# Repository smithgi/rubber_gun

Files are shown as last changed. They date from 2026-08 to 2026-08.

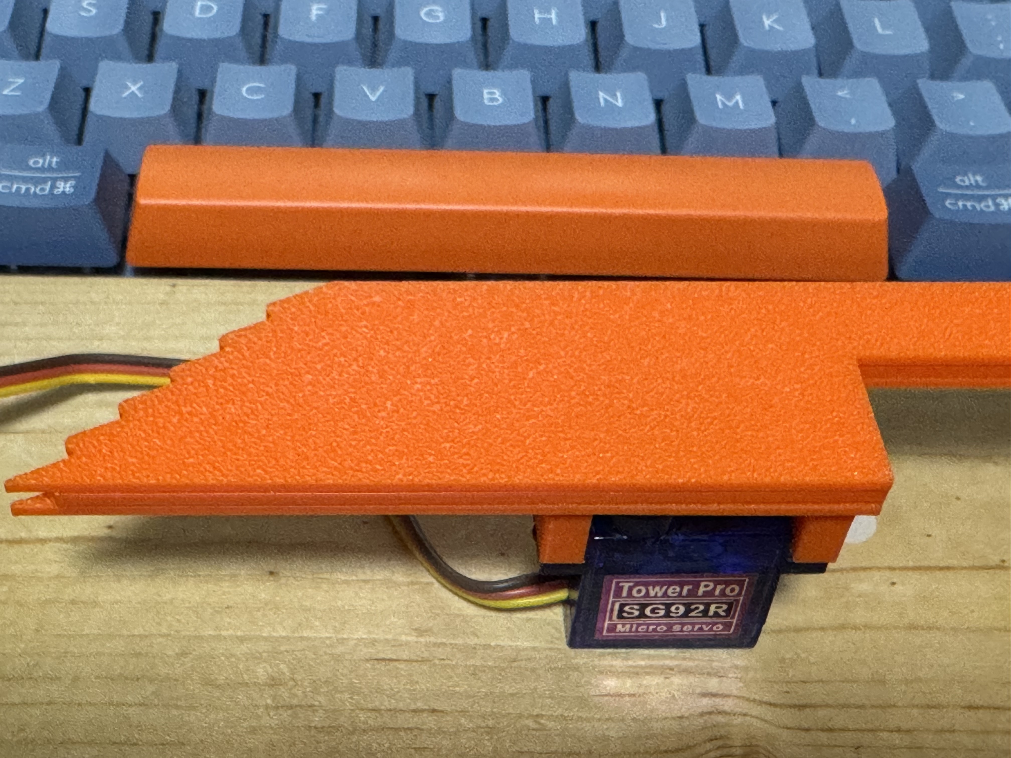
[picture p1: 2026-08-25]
3dParts/Slider Rubber Band Gun - 6731580/images/bcf5f3ab-10ea-41df-92d6-8c3bb40bf381.jpg

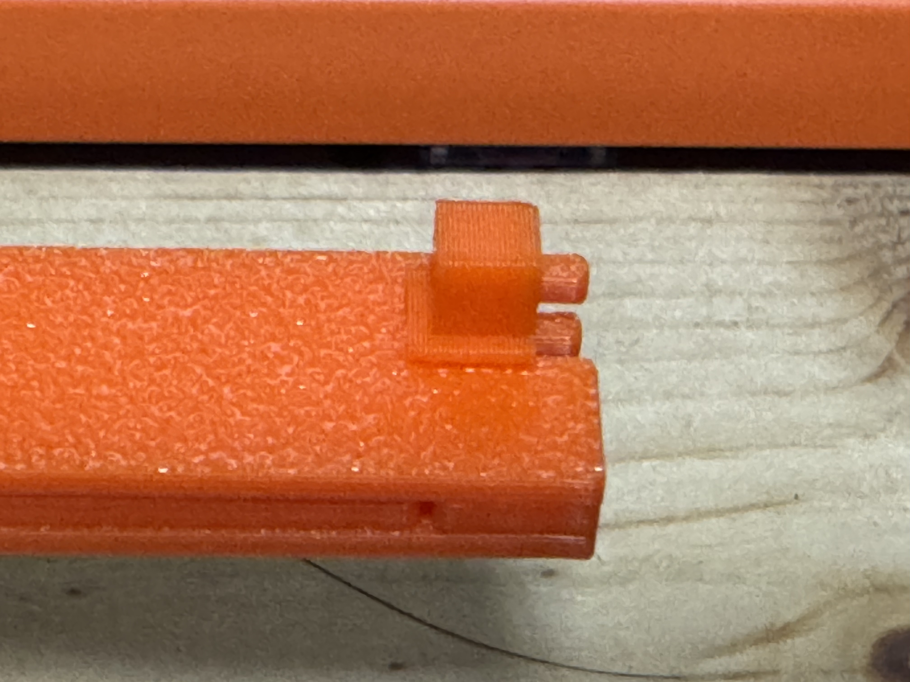
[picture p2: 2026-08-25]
3dParts/Slider Rubber Band Gun - 6731580/images/5f8fa5fe-a7aa-4b6f-bb32-10ab86485eba.jpg

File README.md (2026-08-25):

# Rubber-band radar gun

Standalone rubber-band turret: an RP2040 aims two servos from an RD-03D radar module and fires a third servo on a printed 5-shot slider gun.

Firmware lives in [`RPI2040/`](RPI2040/). Print files live in [`3dParts/`](3dParts/). The Python host and ESP32 sketch are not required.

## What you need

| Item | Notes |
|---|---|
| RP2040-Zero (or Pico) | USB-C powers the MCU only |
| RD-03D radar | UART to GP0 / GP1 |
| 3× micro servos | 9 g SG90 class. SG92R (or equivalent high-torque) is recommended for the trigger |
| External 5 V supply, **≥ 2 A** | Radar VCC + all three servo VCC. Do not power servos from the RP2040 3.3 V pin |
| Printed pan/tilt mount | [`3dParts/2axis_servo.3mf`](3dParts/2axis_servo.3mf) |
| Printed slider gun | [`3dParts/Slider Rubber Band Gun - 6731580/`](3dParts/Slider%20Rubber%20Band%20Gun%20-%206731580/) |
| Rubber bands | Up to 5 on the staircase muzzle |

## Print

### 2-axis servo mount

Open [`3dParts/2axis_servo.3mf`](3dParts/2axis_servo.3mf) in Bambu Studio (or another slicer that reads 3MF). The plate contains three parts:

| Part | Role |
|---|---|
| `base.stl` | Pan/tilt base |
| `HolderL.stl` | Left servo holder |
| `HolderR.stl` | Right servo holder |

The bundled slice is **0.20 mm Standard** on a **Bambu Lab A1**, 0.4 mm nozzle, textured PEI plate:

- Filament: PLA
- Layer height: 0.2 mm
- Walls: 2
- Infill: 15% zig-zag
- Top / bottom shells: 5 / 3
- Supports: tree (auto), slim
- Nozzle / bed: 220 °C / 65 °C

On another printer, match those settings as closely as you can. Print the holders with their flat faces on the bed.

### Slider rubber-band gun

Print the four STLs in [`3dParts/Slider Rubber Band Gun - 6731580/files/`](3dParts/Slider%20Rubber%20Band%20Gun%20-%206731580/files/):

| File | Role |
|---|---|
| `InnerPlate.stl` | Inner plate; servo mounts here |
| `OuterPlate.stl` | Outer plate |
| `TriggerPlate.stl` | Sliding trigger plate |
| `MuzzleRetainer.stl` | Retainer on the muzzle |

Same PLA / 0.2 mm settings work. Print the plates flat on the bed.

This gun is [Slider Rubber Band Gun by Kanten_Namako](https://www.thingiverse.com/thing:6731580) (CC BY-NC-SA). Photos of the assembled plates are in [`3dParts/Slider Rubber Band Gun - 6731580/images/`](3dParts/Slider%20Rubber%20Band%20Gun%20-%206731580/images/).

## Mechanical assembly

### Pan / tilt (TURN + UP)

1. Fit two SG90-class servos into `HolderL` and `HolderR`.
2. Mount the holders on `base` so one servo yaws (TURN, horizontal) and the other pitches (UP, vertical).
3. Attach the slider gun to the moving holder so the muzzle points forward.

On boot the firmware homes UP to `0°` and TURN to `90°`. Mount horns so those angles look like “level and centered.” If the turret is inverted or offset, change `GUN_H_CALIBRATION` and `GUN_V_CALIBRATION` in [`RPI2040/code.py`](RPI2040/code.py).

### Trigger gun

1. Fix the trigger servo on the **inner plate**.
2. Command the servo to **90°**, then attach a servo horn as in the Thingiverse photos.
3. Put the **trigger plate** on the inner plate, then attach the **outer plate**.
4. Attach the **muzzle retainer** to the muzzle.
5. Check motion by sweeping the servo from **90° to 120°**. That should release a band. If torque is weak, load fewer bands.
6. Load rubber bands from the **bottom** of the staircase to the **top**. Maximum five.

Firmware defaults are `TRIGGER_IDLE_DEG = 0` and `TRIGGER_FIRE_DEG = 50`. After the horn is locked at 90°, edit those two constants (or send `{"trigger_pos": …}` over USB) so idle holds the slider and fire matches the 90°→120° release.

## Firmware

1. Install [CircuitPython](https://circuitpython.org/) on the RP2040 so it mounts as `CIRCUITPY`.
2. Copy [`RPI2040/code.py`](RPI2040/code.py) onto that drive. No extra libraries are required (`board`, `busio`, `pwmio` are built in).
3. Leave the board on USB-C. Auto aim/shoot is on at boot (`GUN_ENABLED_ON_BOOT = True`).

Aim math (same policy as the old host):

```
v = distance_mm / 100 + GUN_V_CALIBRATION
h = 180 - radar_angle + GUN_H_CALIBRATION
```

If the radar angle changes, the gun aims. If the next frame reports the same angle, it fires a burst (`BURST_NUM = 2`).

## Wiring

Full diagram: [`RPI2040/wiring.svg`](RPI2040/wiring.svg) / [`RPI2040/wiring.png`](RPI2040/wiring.png).

| Function | RP2040 pin | Goes to |
|---|---|---|
| Radar TX | GP0 | RD-03D **RX** |
| Radar RX | GP1 | RD-03D **TX** |
| Turn servo (h) | GP2 | TURN servo **SIG** (orange / yellow) |
| Up servo (v) | GP3 | UP servo **SIG** (orange / yellow) |
| Trigger servo | GP4 | TRIGGER servo **SIG** (orange / yellow) |
| Common ground | GND | PSU GND + radar GND + all 3 servo GND (brown / black) |
| Servo / radar power | external **5 V** | radar VCC + all 3 servo VCC (red) |

```
                    USB-C (powers the RP2040 only)
                         │
                         ▼
                   ┌─────────────┐
  RD-03D TX ──────►│ GP1  RX     │
  RD-03D RX ◄──────│ GP0  TX     │
                   │             │ GP2 ── SIG ── TURN servo
                   │ RP2040-Zero │ GP3 ── SIG ── UP servo
                   │             │ GP4 ── SIG ── TRIGGER servo
                   │ GND         │
                   └──────┬──────┘
                          │
     common GND ──────────┼────────── PSU GND
                          │
     5V PSU (≥2A) ── +5V ─┴── radar VCC + 3× servo VCC (red)

     Every brown/black servo wire → the same GND star.
     Do not power servos from the RP2040 3.3 V pin.
```

UART names are crossed on purpose: module TX goes to MCU RX. Radar baud is 256000.

### Power rules

1. Tie every GND together: PSU, RP2040, RD-03D, and all three servos. Without a common ground the PWM signals will not reference the servos.
2. Keep the RP2040 on USB-C. Power the three servos and the RD-03D VCC from the **separate 5 V, ≥ 2 A** supply.
3. Never feed servo VCC from the RP2040 3.3 V pin. Current spikes will brown-out the MCU.
4. 3.3 V PWM on GP2 / GP3 / GP4 is enough for most hobby servos.

## USB serial (optional)

Open the CircuitPython REPL / serial monitor:

| Command | Effect |
|---|---|
| `start` or `{"start":true}` | enable auto aim/shoot |
| `stop` or `{"stop":true}` | disable auto aim/shoot |
| `{"h":90,"v":40}` | manual aim |
| `{"shoot":true}` | one trigger pull |
| `{"trigger_pos":50}` | set trigger servo degrees |

Radar frames still print as JSON arrays.

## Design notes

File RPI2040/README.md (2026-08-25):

# RP2040 standalone radar gun

Runs the whole stack on one RP2040 (RP2040-Zero / Pico):

- talk to the RD-03D on UART
- aim `TURN` + `UP` servos
- fire the `TRIGGER` servo

The Python host (`main.py`) and the ESP32 sketch (`arduino_gun.ino`) are not needed.

Copy `code.py` onto the CircuitPython `CIRCUITPY` drive.

## Pin map

| Function | RP2040 pin | Goes to |
|---|---|---|
| Radar TX | GP0 | RD-03D **RX** |
| Radar RX | GP1 | RD-03D **TX** |
| Turn servo (h) | GP2 | Turn servo **SIG** (orange) |
| Up servo (v) | GP3 | Up servo **SIG** (orange) |
| Trigger servo | GP4 | Trigger servo **SIG** (orange) |
| Common ground | GND | PSU GND + radar GND + all 3 servo GND |
| Servo / radar power | external **5V** | radar VCC + all 3 servo VCC (red) |

See `wiring.svg` and `wiring.png`.

## Wiring sketch

```
                    USB-C (powers the RP2040 only)
                         │
                         ▼
                   ┌─────────────┐
  RD-03D TX ──────►│ GP1  RX     │
  RD-03D RX ◄──────│ GP0  TX     │
                   │             │ GP2 ── SIG ── TURN servo
                   │ RP2040-Zero │ GP3 ── SIG ── UP servo
                   │             │ GP4 ── SIG ── TRIGGER servo
                   │ GND         │
                   └──────┬──────┘
                          │
     common GND ──────────┼────────── PSU GND
                          │
     5V PSU (≥2A) ── +5V ─┴── radar VCC + 3× servo VCC (red)

     Every brown/black servo wire → the same GND star.
     Do not power servos from the RP2040 3.3V pin.
```

UART names are crossed on purpose: module TX goes to MCU RX.

## Power

- Keep the RP2040 on USB-C.
- Power the three servos (and the RD-03D VCC) from a **separate 5 V supply, 2 A or more**.
- Tie all grounds together. Without a common GND the PWM signals will not reference the servos.

## Aim / shoot (same as `main.py`)

```
v = distance_mm / 100 + GUN_V_CALIBRATION
h = 180 - radar_angle + GUN_H_CALIBRATION
```

If the radar angle changes, the gun aims. If the next frame reports the same angle, it fires a burst.

Defaults match `.env`: `GUN_H_CALIBRATION=-30`, `GUN_V_CALIBRATION=-10`, `BURST_NUM=2`. Edit the constants at the top of `code.py`.

## USB serial (optional)

115200-style CircuitPython REPL / serial monitor:

| Command | Effect |
|---|---|
| `start` or `{"start":true}` | enable auto aim/shoot |
| `stop` or `{"stop":true}` | disable auto aim/shoot |
| `{"h":90,"v":40}` | manual aim |
| `{"shoot":true}` | one trigger pull |
| `{"trigger_pos":50}` | set trigger servo degrees |

Radar frames still print as JSON arrays, same as the old RP2040 bridge.

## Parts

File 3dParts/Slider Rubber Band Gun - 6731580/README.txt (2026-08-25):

Slider Rubber Band Gun by Kanten_Namako on Thingiverse: https://www.thingiverse.com/thing:6731580

Summary:
A servo motor (SG90 sized) operated 5-shot rubber band gunUsing high torque servo, SG92R or equivalent is recommended.Fix the servo motor on the inner plate and rotate the servo to the 90° position, then attach a servo horn as shown in the picture.Put the trigger plate on the inner plate, then attach outer plate. Attach a muzzle retainer to the muzzle.Check the function by moving the servo from 90° to 120° .Load the rubber bands from the bottom of the staircase-shaped component to the top.A maximum of five rubber bands can be attached.To release the rubber bands, move the servo motor from 90° to 120°.https://youtu.be/MrI2VKSIGMsIf the torque of the servo motor is weak, it can be operated by reducing the number of rubber bands.

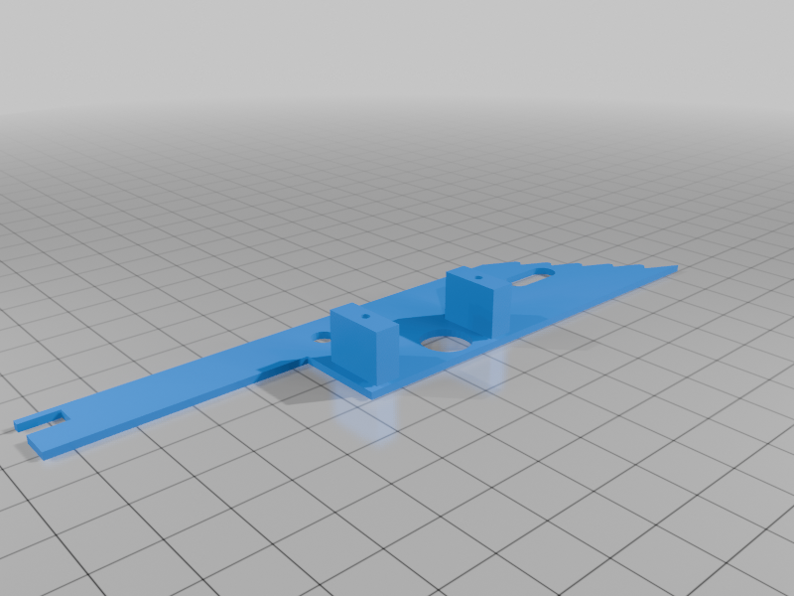
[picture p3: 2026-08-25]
3dParts/Slider Rubber Band Gun - 6731580/images/c03b1915-364d-412d-94fc-ef0b91e72bb4.png

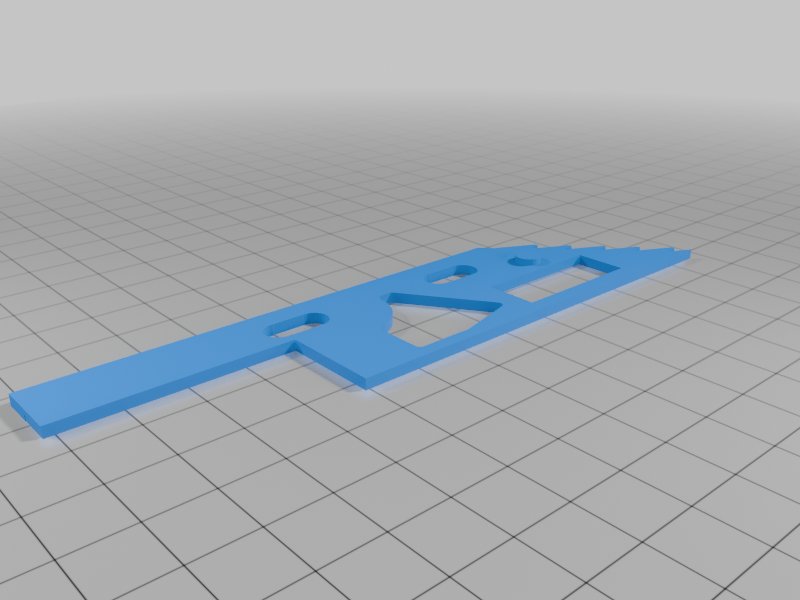
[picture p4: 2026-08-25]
3dParts/Slider Rubber Band Gun - 6731580/images/888463a6-bb99-47a2-ad43-ac800f5a4983.png

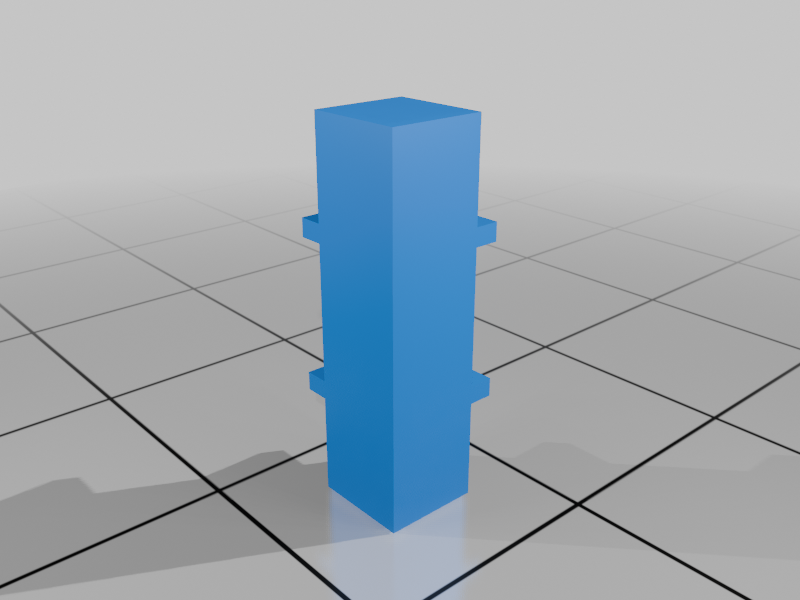
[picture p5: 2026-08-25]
3dParts/Slider Rubber Band Gun - 6731580/images/fcaf6c9f-c65c-43a0-b7bd-5645cbccdeec.png

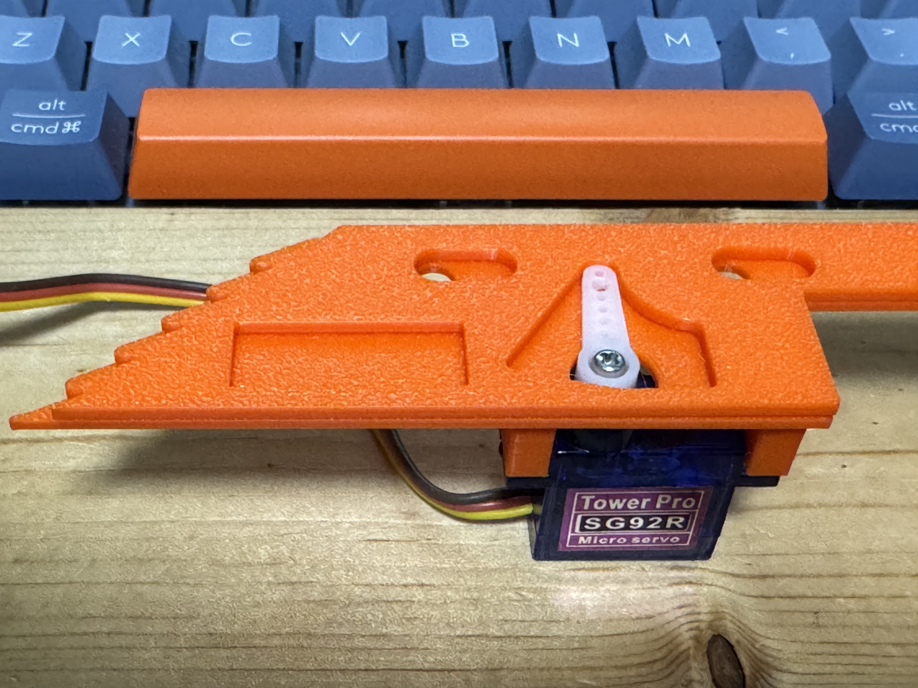
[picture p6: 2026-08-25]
3dParts/Slider Rubber Band Gun - 6731580/images/9d21aa52-659c-4183-8837-1a03f21f6c0c.jpg

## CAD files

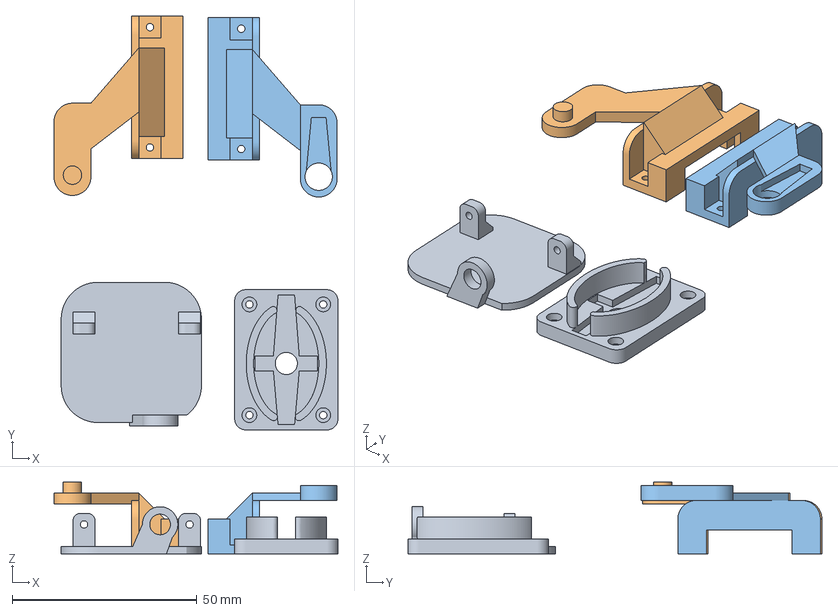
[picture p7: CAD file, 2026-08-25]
3dParts/2axis_servo.3mf
76.9 x 112.1 x 19.5 mm
base.stl
HolderL.stl
HolderR.stl

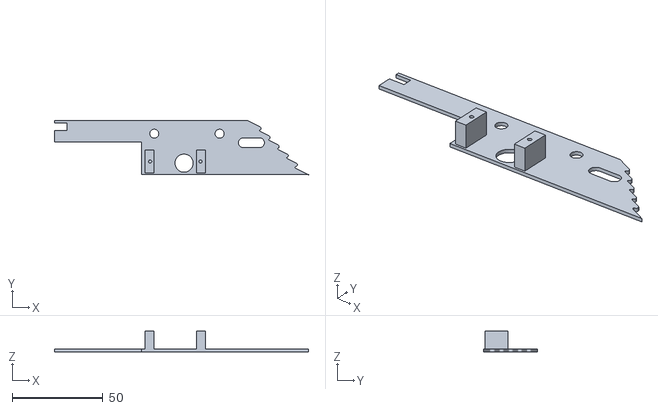
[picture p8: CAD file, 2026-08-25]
3dParts/Slider Rubber Band Gun - 6731580/files/InnerPlate.stl
140.0 x 30.0 x 11.5

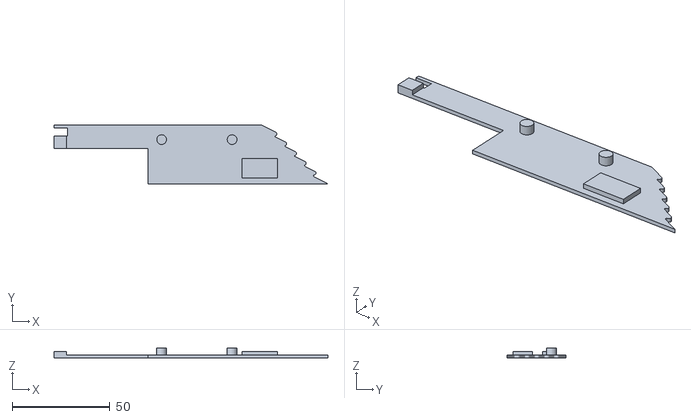
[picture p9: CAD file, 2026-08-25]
3dParts/Slider Rubber Band Gun - 6731580/files/OuterPlate.stl
140.0 x 30.0 x 5.00

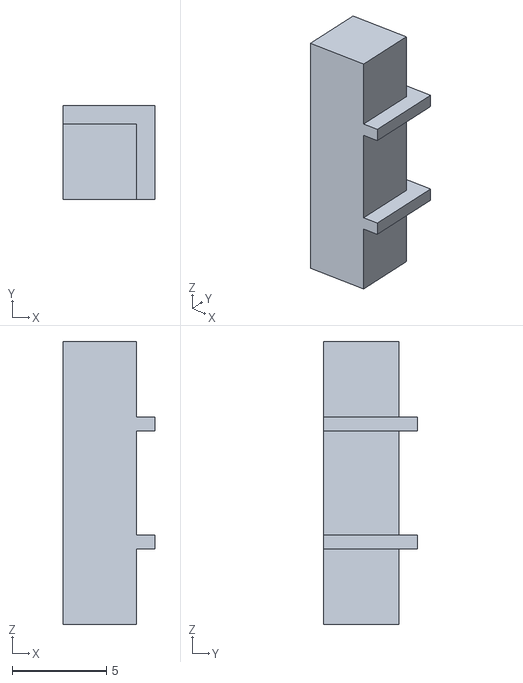
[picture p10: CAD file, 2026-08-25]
3dParts/Slider Rubber Band Gun - 6731580/files/MuzzleRetainer.stl
4.90 x 5.00 x 15.0

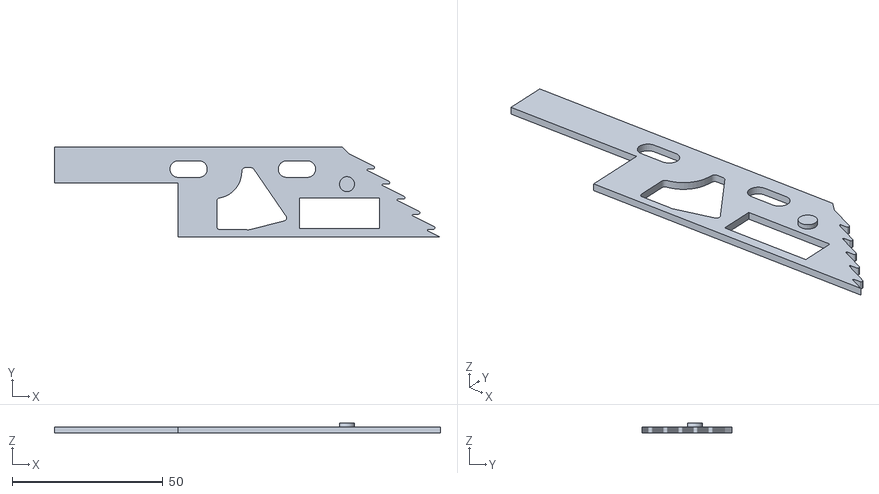
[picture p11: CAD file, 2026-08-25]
3dParts/Slider Rubber Band Gun - 6731580/files/TriggerPlate.stl
128.2 x 30.0 x 3.28

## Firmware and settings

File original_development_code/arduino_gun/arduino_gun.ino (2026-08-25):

#include <ESP32Servo.h>
#include <string.h>

Servo upServo;
Servo turnServo;
Servo triggerServo;

const int SERVO1_PIN = 18;
const int SERVO2_PIN = 19;
const int TRIGGER_SERVO_PIN = 5;

const int TRIGGER_FIRE_DEG = 50;
const int TRIGGER_IDLE_DEG = 0;

int upServoPos = 90;
int turnServoPos = 90;
int triggerServoPos = TRIGGER_IDLE_DEG;

int upServoStartPos = 0;
int turnServoStartPos = 90;

int servoSpeed = 1;

bool useFastMovement = true;

// UART command buffer: {"h":90,"v":90}
#define CMD_BUFFER_LEN 64
char cmdBuffer[CMD_BUFFER_LEN];

bool parseJsonAngles(char* buf, int* turnAngle, int* upAngle) {
  // Format: {"h":<angle>,"v":<angle>}
  int h = -1, v = -1;
  char* p;

  if ((p = strstr(buf, "\"h\":")) != NULL || (p = strstr(buf, "\"H\":")) != NULL) {
    p += 4;  // skip past "h":
    h = atoi(p);
  }
  if ((p = strstr(buf, "\"v\":")) != NULL || (p = strstr(buf, "\"V\":")) != NULL) {
    p += 4;  // skip past "v":
    v = atoi(p);
  }

  if (h >= 0 && h <= 180 && v >= 0 && v <= 180) {
    *turnAngle = h;
    *upAngle = v;
    return true;
  }
  return false;
}

bool parseShoot(char* buf) {
  char* p = strstr(buf, "\"shoot\":");
  if (p == NULL) {
    p = strstr(buf, "\"SHOOT\":");
  }
  if (p == NULL) return false;
  p += 8;
  while (*p == ' ' || *p == '\t') p++;
  return strncmp(p, "true", 4) == 0;
}

bool parseTriggerPos(char* buf, int* deg) {
  char* p = strstr(buf, "\"trigger_pos\"");
  if (p == NULL) p = strstr(buf, "\"TRIGGER_POS\"");
  if (p == NULL) return false;
  p = strchr(p, ':');
  if (p == NULL) return false;
  p++;
  while (*p == ' ' || *p == '\t') p++;
  int v = atoi(p);
  if (v >= 0 && v <= 180) {
    *deg = v;
    return true;
  }
  return false;
}

void fireTrigger() {
  triggerServo.write(TRIGGER_FIRE_DEG);
  triggerServoPos = TRIGGER_FIRE_DEG;
  delay(500);
  triggerServo.write(TRIGGER_IDLE_DEG);
  triggerServoPos = TRIGGER_IDLE_DEG;
}

void setup() {
  Serial.begin(115200);

  upServo.setPeriodHertz(50);
  turnServo.setPeriodHertz(50);
  triggerServo.setPeriodHertz(50);

  upServo.attach(SERVO1_PIN, 500, 2400);
  turnServo.attach(SERVO2_PIN, 500, 2400);
  triggerServo.attach(TRIGGER_SERVO_PIN, 500, 2400);

  upServo.write(upServoPos);
  turnServo.write(turnServoPos);
  triggerServo.write(TRIGGER_IDLE_DEG);
  triggerServoPos = TRIGGER_IDLE_DEG;

  moveSmooth(upServo, upServoPos, upServoStartPos, servoSpeed);
  moveSmooth(turnServo, upServoPos, turnServoStartPos, servoSpeed);

  delay(1000);
}

void loop() {
  // Read UART commands: {"h":90,"v":90}
  if (Serial.available() > 0) {
    int idx = 0;
    memset(cmdBuffer, 0, CMD_BUFFER_LEN);

    while (Serial.available() > 0 && idx < CMD_BUFFER_LEN - 1) {
      char c = Serial.read();
      if (c == '\n' || c == '\r') break;
      cmdBuffer[idx++] = c;
    }
    cmdBuffer[idx] = '\0';

    if (idx > 0) {
      int newTurn, newUp;
      int triggerDeg;
      bool anglesOk = parseJsonAngles(cmdBuffer, &newTurn, &newUp);
      bool shoot = parseShoot(cmdBuffer);
      bool triggerPosOk = parseTriggerPos(cmdBuffer, &triggerDeg);

      if (!anglesOk && !shoot && !triggerPosOk) {
        Serial.println("{\"err\":\"invalid\"}");
      } else {
        if (anglesOk) {
          if (useFastMovement) {
            moveFast(turnServo, newTurn);
            turnServoPos = newTurn;

            moveFast(upServo, newUp);
            upServoPos = newUp;

            Serial.printf("{\"h\":%d,\"v\":%d}\n", newTurn, newUp);
          } else {
            moveSmooth(turnServo, turnServoPos, newTurn, servoSpeed);
            turnServoPos = newTurn;

            moveSmooth(upServo, upServoPos, newUp, servoSpeed);
            upServoPos = newUp;

            Serial.printf("{\"h\":%d,\"v\":%d}\n", turnServoPos, upServoPos);
          }
        }
        if (triggerPosOk) {
          moveFast(triggerServo, triggerDeg);
          triggerServoPos = triggerDeg;
        }
        if (shoot) {
          fireTrigger();
        }
        if (!anglesOk) {
          if (triggerPosOk && shoot) {
            Serial.printf("{\"trigger_pos\":%d,\"shoot\":true}\n", triggerDeg);
          } else if (triggerPosOk) {
            Serial.printf("{\"trigger_pos\":%d}\n", triggerDeg);
          } else if (shoot) {
            Serial.println("{\"shoot\":true}");
          }
        }
      }
    }
  }
  delay(10);
}

void moveSmooth(Servo &servo, int fromPos, int toPos, int stepDelayMs) {
  if (fromPos < toPos) {
    for (int pos = fromPos; pos <= toPos; pos++) {
      servo.write(pos);
      delay(stepDelayMs);
    }
  } else {
    for (int pos = fromPos; pos >= toPos; pos--) {
      servo.write(pos);
      delay(stepDelayMs);
    }
  }
}

void moveFast(Servo &servo, int toPos) {
  servo.write(toPos);
}

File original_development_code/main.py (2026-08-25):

import logging
import serial
import signal
import sys
import time

from config import LOG_LEVEL, GUN_H_CALIBRATION, GUN_V_CALIBRATION, BURST_NUM
logging.basicConfig(level=LOG_LEVEL, format="%(asctime)s - %(name)s - %(levelname)s - %(message)s")

logger = logging.getLogger(__name__)
import tty
import termios
import threading
import math
import struct
from alarm import AlarmAgent
#from radar import RadarInterface
import sys
from PyQt6.QtWidgets import (
    QApplication,
    QMainWindow,
    QWidget,
    QVBoxLayout,
    QHBoxLayout,
    QPushButton,
    QLabel,
)
from PyQt6.QtCore import QThread, QEvent, QTimer
from PyQt6.QtGui import QPen, QColor, QFont
from rd_03d import RD03D
from rd_03d_json import RD03DJson
from arduino_gun.arduino_gun import ArduinoGun
from PyQt6.QtWidgets import QGraphicsView, QGraphicsScene
from stick_figure import StickFigure
from alarm_generator import AssetMonitor


USE_MULTI_TARGET_DETECTION = False

# Configure the serial port
class RadarModule(QMainWindow):
    def __init__(self):
        super().__init__()
        #self.rd03d = RD03D()
        self.rd03d = RD03DJson()
        self.size = 1980
        #self.radar_interface = RadarInterface() 
        """
        if USE_MULTI_TARGET_DETECTION:
            self.rd03d.send_command(Multi_Target_Detection_CMD)
        else:
            self.rd03d.send_command(Single_Target_Detection_CMD)
        """

        self.alarm_stream_data = ""

        #self.asset_monitor = AssetMonitor(self.size/2, self.size/2)
        #self.start_radar_interface()

        #self.add_target_to_radar_interface(100, 100, 0, 0)

        #self.alarm_agent = AlarmAgent()
        self.keep_running = True
        #self.start_quit_listener()
        self.rd03d_thread = threading.Thread(target=self.rd03d.read_data, daemon=True)
        self.rd03d_thread.start()

        self.rd03d.item_added.connect(self.handle_item_added)
        self.last_angle = None
        try:
            self.arduino_gun = ArduinoGun()
        except Exception as e:
            logger.warning("Arduino gun not available: %s", e)
            self.arduino_gun = None
        self.gun_enabled = False
        self.init_ui()

    def init_ui(self):
        self.setWindowTitle("Radar Gun Control")

        central = QWidget()
        layout = QVBoxLayout(central)
        layout.setContentsMargins(8, 8, 8, 8)

        self.radar_view = QGraphicsView()
        self.scene = QGraphicsScene(self)
        self.radar_view.setScene(self.scene)

        # Set the scene rect to ensure the circle is within view
        self.scene.setSceneRect(0, 0, self.size, self.size)

        self.status_label = QLabel()
        self.action_label = QLabel("")
        self.action_label.setMinimumWidth(160)
        self.action_label.setStyleSheet(
            "QLabel { color: #ff1744; font-weight: bold; font-size: 22px; }"
        )
        self.start_button = QPushButton("Start")
        self.start_button.setMinimumWidth(120)
        self.start_button.setStyleSheet(
            "QPushButton { background-color: #2e7d32; color: white; font-weight: bold; padding: 8px; }"
            "QPushButton:disabled { background-color: #555; color: #aaa; }"
        )
        self.start_button.clicked.connect(self.start_gun)

        self.stop_button = QPushButton("Stop")
        self.stop_button.setMinimumWidth(120)
        self.stop_button.setStyleSheet(
            "QPushButton { background-color: #c62828; color: white; font-weight: bold; padding: 8px; }"
            "QPushButton:disabled { background-color: #555; color: #aaa; }"
        )
        self.stop_button.clicked.connect(self.stop_gun)

        controls = QHBoxLayout()
        controls.addWidget(self.status_label)
        controls.addStretch()
        controls.addWidget(self.action_label)
        controls.addStretch()
        controls.addWidget(self.start_button)
        controls.addWidget(self.stop_button)

        layout.addWidget(self.radar_view, stretch=1)
        layout.addLayout(controls)
        self.setCentralWidget(central)

        self.draw_lines()
        self.draw_meters()
        self.draw_circle(self.size/2, self.size/2)
        self._update_gun_controls()
        self.show()

    def start_gun(self):
        if not self.arduino_gun:
            logger.warning("Cannot start: Arduino gun not available")
            return
        self.gun_enabled = True
        logger.info("Gun operation started")
        self._update_gun_controls()

    def stop_gun(self):
        self.gun_enabled = False
        logger.info("Gun operation stopped (moving and shooting disabled)")
        self._update_gun_controls()

    def _update_gun_controls(self):
        available = self.arduino_gun is not None
        self.start_button.setEnabled(available and not self.gun_enabled)
        self.stop_button.setEnabled(available and self.gun_enabled)
        if not available:
            self.status_label.setText("Gun: UNAVAILABLE")
            self._set_action("")
        elif self.gun_enabled:
            self.status_label.setText("Gun: RUNNING")
        else:
            self.status_label.setText("Gun: STOPPED")
            self._set_action("")

    def _set_action(self, text):
        self.action_label.setText(text)
        QApplication.processEvents()

    def handle_item_added(self, x, y, distance, angle):
        #print(f"Item added: {x, y, distance, angle}")
        self.delete_previous_circle()
        #self.draw_circle(x+self.size/2, y)
        self.scene.addItem(StickFigure(int(x+self.size/2), int(y)))
        #self.asset_monitor.add_coordinates(x, y)

        if not self.arduino_gun or not self.gun_enabled:
            return
        if self.last_angle != angle:
            self.last_angle = angle
            try:
                logger.debug("Moving gun to angle: %s, distance: %s", angle, distance)
                v = int(distance/100) + GUN_V_CALIBRATION
                callicrated_angle = 180 - angle + GUN_H_CALIBRATION
                self.arduino_gun.move(h=int(callicrated_angle), v=v)
            except Exception as e:
                logger.error("Failed to send angle to arduino gun: %s", e)
        elif self.last_angle is not None:
            try:
                logger.info("Target still at angle %s — shooting", angle)
                self._set_action("Burst")
                #self.arduino_gun.shoot()
                self.arduino_gun.burst_shoot(BURST_NUM)
                #time.sleep(0.5)
                #self.arduino_gun.shoot()
            except Exception as e:
                logger.error("Failed to shoot: %s", e)
            finally:
                self._set_action("")

    def delete_previous_circle(self):
        # Assuming the last added item is the circle to be deleted
        if self.scene.items():
            last_item = self.scene.items()[0]  # Get the last added item
            self.scene.removeItem(last_item)
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

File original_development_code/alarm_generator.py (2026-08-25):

import logging

logger = logging.getLogger(__name__)


class AssetMonitor:
    def __init__(self, asset_x, asset_y, buffer_size=20, approach_threshold=10):
        self.asset_x = asset_x
        self.asset_y = asset_y
        self.buffer_size = buffer_size
        self.coordinates_buffer = []
        self.approach_threshold = approach_threshold

    def add_coordinates(self, x, y):
        if len(self.coordinates_buffer) >= self.buffer_size:
            self.coordinates_buffer.pop(0)
        self.coordinates_buffer.append((x, y))
        self.check_approaching()

    def check_approaching(self):
        if len(self.coordinates_buffer) < 8:
            return

        initial_x, initial_y = self.coordinates_buffer[0]
        final_x, final_y = self.coordinates_buffer[-1]

        initial_distance = self.calculate_distance(initial_x, initial_y)
        final_distance = self.calculate_distance(final_x, final_y)

        if initial_distance - final_distance > self.approach_threshold:
            logger.info("Alert: The item is approaching the asset!")

    def calculate_distance(self, x, y):
        return ((x - self.asset_x) ** 2 + (y - self.asset_y) ** 2) ** 0.5
